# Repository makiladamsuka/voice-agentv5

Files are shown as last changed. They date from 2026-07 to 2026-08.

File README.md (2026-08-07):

# Nema — Multimodal Autonomous Campus Kiosk Robot

Nema is an end-to-end autonomous campus kiosk robot featuring real-time computer vision, closed-loop kinematic motor positioning, dynamic eye animations, 4-DOF greeting gestures, and a zero-latency natural language voice agent interface.

---

## 📸 Kiosk User Interface Screenshots

### 1. Main Campus Announcement Hub
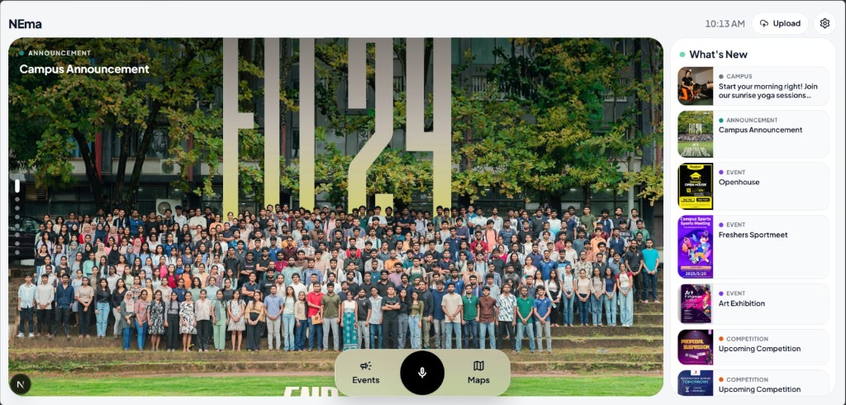
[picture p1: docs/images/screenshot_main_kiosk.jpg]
Main Campus Announcement Hub


### 2. Events & Competitions Grid
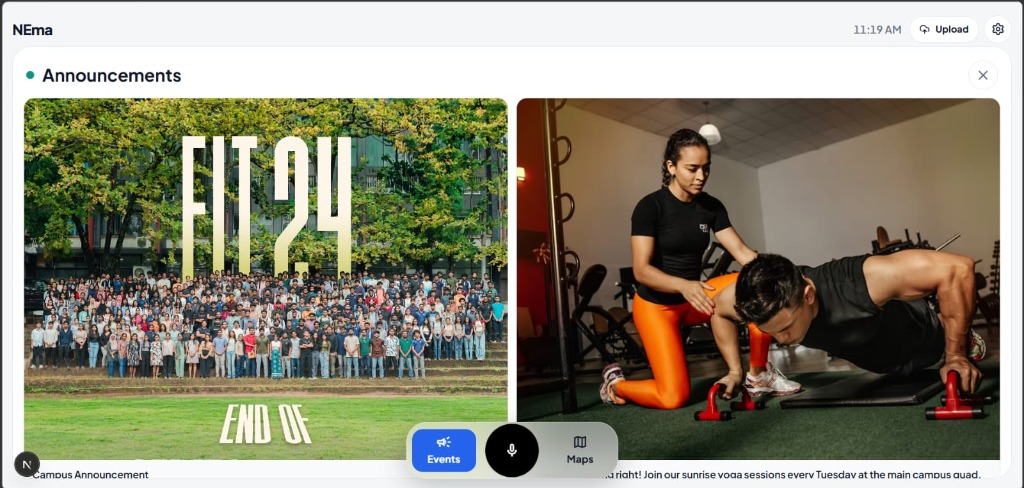
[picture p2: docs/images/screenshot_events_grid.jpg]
Events Grid


### 3. Tap-to-Talk Interactive Voice Chat
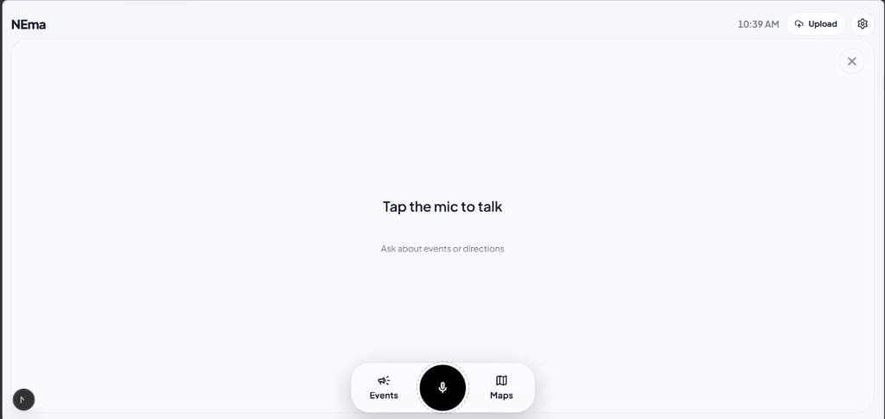
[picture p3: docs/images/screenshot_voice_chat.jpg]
Voice Chat


### 4. Interactive 3D Campus Maps
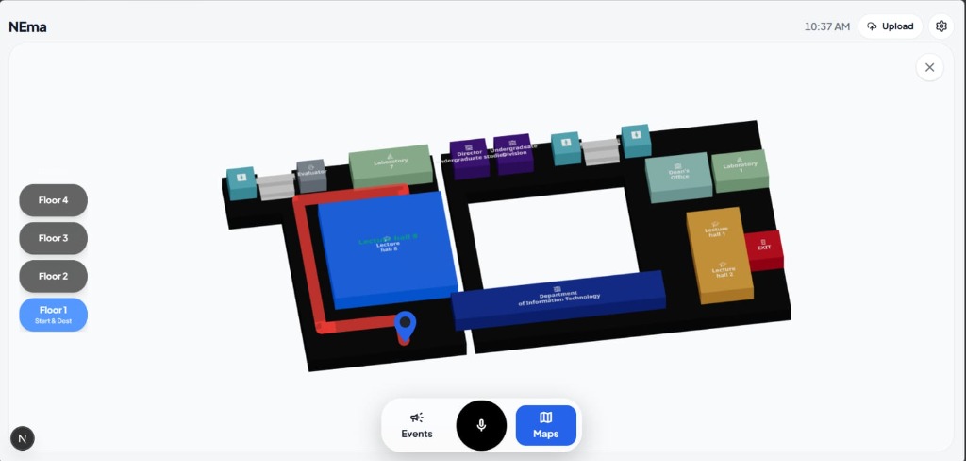
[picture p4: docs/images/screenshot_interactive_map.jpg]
Interactive Maps


### 5. Quick Destination & Faculty Navigation
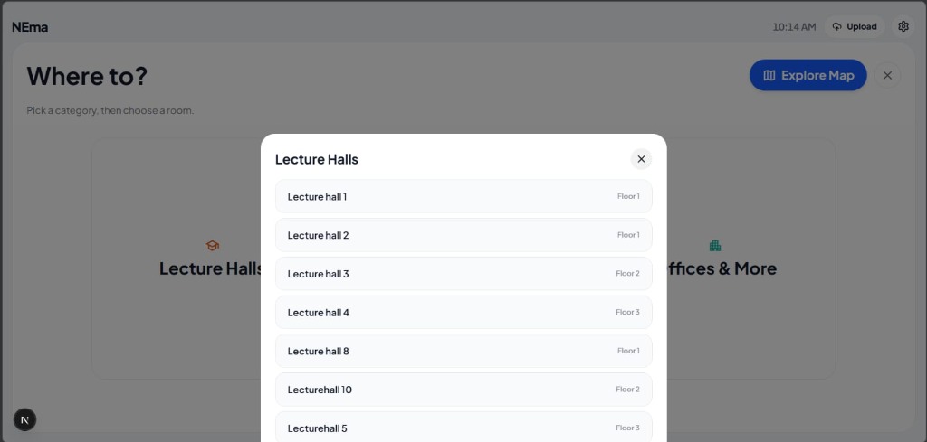
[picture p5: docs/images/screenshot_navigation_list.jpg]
Destination Navigation


---

## 📂 Quick Links & Documentation

- **🚀 [Quick Start & Setup Guide](docs/QUICK_START.md)** — Complete step-by-step instructions for fresh Raspberry Pi setup, config settings, and starting the kiosk stack.
- **🧠 [System Architecture & Specifications](docs/SYSTEM_ARCHITECTURE.md)** — Exhaustive technical details covering CPU core affinity, custom PCBs, Blackboard state bus, and NLU vector matching.
- **📦 [3D Printable STL Parts](hardware/3d_models/)** — 3D model files (.stl) for Nema's custom robot body and mounts.

---

## 🛠️ Hardware Stack Overview

- **Raspberry Pi 4 Model B (Brain):** Runs face-tracking, emotion engines, and the Next.js kiosk frontend.
- **ESP32 DevKit V1 (Muscles):** Controls servos (head pan/tilt, 4-DOF arms) and closed-loop DC base motors.
- **Raspberry Pi Zero 2 W (Voice Node):** Dedicated low-noise voice module running an INMP441 MEMS microphone.
- **3 Custom PCBs:** Custom circuit boards for the Pi 4 (eye screen outputs), ESP32 (motor control lines), and Pi Zero (mic module).

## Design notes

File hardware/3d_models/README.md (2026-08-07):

# Nema Kiosk Robot — 3D Component Models

Place your 3D printer files and CAD designs in this directory.

## Directory Structure

- `stl_parts/`  
  *Place your printable `.stl` or `.3mf` files here. These will render interactively directly in the web browser on GitHub.*

## Printing Guidelines (Recommended)

- **Filament:** PLA or PETG (PETG is recommended for load-bearing brackets and joints).
- **Infill:** 15% to 25% (Gyro / Grid infill for strength).
- **Supports:** Enable supports for overhang brackets.

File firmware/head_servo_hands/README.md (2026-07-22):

# head_servo_hands

**Baseline `head_servo` + four arm servos.** Same head/base protocol as `firmware/head_servo/`
(L/R spin, encoder moves, U/RL limit unlock, etc.) — face tracking keeps working.

## PCA9685 wiring

| PCA ch | Token | Servo |
|---|---|---|
| 4 | P | pan |
| 5 | T | tilt |
| 0 | A0 | MG996R_R — right shoulder raise |
| 2 | A1 | MG996R_L — left shoulder raise |
| 8 | A2 | SG90_R — right arm sweep |
| 9 | A3 | SG90_L — left arm sweep |

## Arm limits (deg) and home

| Servo | Min | Max | Home |
|---|-----|-----|---|
| A0 (R raise) | 47 | 124 | 47 |
| A1 (L raise) | 6 | 65 | 65 (rest down; lower angle = raised) |
| A2 (R sweep) | 44 | 78 | 64 |
| A3 (L sweep) | 70 | 102 | 87 |

Home = captured **raise low + min sweep** pose (`tests/captured_arm_limits.json`).

I2C: SDA=21, SCL=22, address `0x40`, 115200 baud USB serial.

## Flash

```bash
arduino-cli upload -p /dev/ttyUSB0 --fqbn esp32:esp32:esp32 firmware/head_servo_hands
```

Boot banner: `FW head_servo_hands_v5`

Arm PWM is **off at boot** until the Pi sends `A0..A3`. After **30 s** without an arm command, PWM turns off (Pi keepalive should send every &lt;1 s). Send `AO` to detach immediately. Head pan/tilt (ch 4/5) unchanged.

## Test arms

```bash
python tests/test_servo_arms_manual.py
```

## Note

`firmware/head_servo/head_servo.ino` stays head-only for `main`/baseline.
Flash this sketch when arms are connected; `start_robot.py` needs no code changes.

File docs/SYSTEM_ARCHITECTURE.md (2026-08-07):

# Voice Agent V5 — System Architecture & Technical Specification

**Project Title:** Voice Agent V5: Multimodal Autonomous Kiosk Robot  
**Document Version:** 5.4.0  
**Target Audience:** University Dean, Academic Evaluation Committee, Systems Architecture & Robotics Engineering Team  
**Author / Engineering Lead:** Voice Agent V5 Project Team  
**Date:** August 2026  

---

## 📋 Executive Summary & System Overview

**Voice Agent V5** is an integrated, end-to-end multimodal autonomous kiosk and physical robotic head/arm platform. Designed for high-foot-traffic campus environments, the system combines real-time computer vision, closed-loop kinematic motion control, sensor fusion, natural language understanding (NLU), and procedural graphics to deliver zero-latency human-robot interactions (HRI).

### Key Architectural Highlights
1. **Multimodal Perception Array:** Computer vision via OpenCV YuNet neural face detection, Bosch BMI160 6-DOF head IMU stabilization, and 3-zone ST VL53L0X Time-of-Flight (ToF) laser ranging via a TCA9548A I2C multiplexer.
2. **Centralized Shared-Memory Blackboard Architecture:** Decoupled thread-safe state bus (`core/blackboard.py`) using lock-free read concepts and CPU-friendly condition variables (`wait_for`) to eliminate polling latency while running at 0% idle CPU overhead.
3. **Distributed Hardware Controller Bridge:** Dedicated ESP32 NodeMCU microcontroller managing physical actuators (head pan/tilt, 4-DOF robotic arms, TB6612FNG motor driver base spin) via high-speed custom binary/ASCII serial wire protocol over USB UART.
4. **Zero-Latency NLU & Pre-Synthesized Speech Pipeline:** Local ChromaDB vector database with pre-synthesized 48kHz uncompressed audio cache combined with online LLM (Groq/OpenRouter) and offline local fallback runtime.
5. **Interactive Touchscreen Kiosk UI:** Next.js 14 React frontend rendering event posters, interactive maps, live voice waveforms, and real-time face greeting overlays.

```mermaid
graph TD
    subgraph "Perception Layer"
        CAM[GC2053 / Pi Camera v2] -->|Picamera2 / OpenCV| VT[YuNet Face & Hand Tracker]
        IMU[BMI160 6-DOF IMU] -->|Pi I2C 1 @ 0x69| IS[ImuService - Complementary Filter]
        TOF[3x VL53L0X ToF Array] -->|TCA9548A Mux @ 0x70| ESP32[ESP32 Microcontroller]
        MIC[Dedicated Pi Zero 2 W / INMP441 Mic] -->|Web Audio / Silero VAD| VA[Voice & NLU Pipeline]
    end

    subgraph "Core Decoupled Shared Memory"
        BB[(Blackboard Shared State Bus)]
    end

    subgraph "Actuation & Control Layer"
        SL[ServoLoop - Head PID & Wander]
        BC[BaseController - Closed-loop Fusion]
        AC[ArmController - Safety Envelope & Poses]
        EE[EmotionEngine - Mood State Machine]
        ER[EyeRenderer - 60FPS Procedural TFT]
    end

    subgraph "Hardware Communication Bridge"
        ASL[ArduinoServoLink Transport]
        PCA[PCA9685 PWM Driver @ 0x40]
        MOT[TB6612FNG Base Motor Driver]
    end

    VT -->|Write Bounding Box & Norm X/Y| BB
    IS -->|Write Roll/Pitch & Gyro Yaw| BB
    ESP32 -->|Stream PROX / ZONE Telemetry| ASL
    ASL -->|Write Proximity Vectors| BB
    VA -->|Write Voice State & RMS Amp| BB

    BB <-->|Read Targets / Write Pose| SL
    BB <-->|Read Pan Limit / Write Base Step| BC
    BB <-->|Read Gesture / Write Arm Joint Angles| AC
    BB <-->|Read Voice/Sensing / Write Mood| EE
    BB <-->|Read Emotion / Render TFT| ER

    SL -->|Pan/Tilt Cmds| ASL
    BC -->|Base Spin Cmds| ASL
    AC -->|Arm A0-A3 Cmds| ASL

    ASL <-->|USB Serial UART @ 115200| ESP32
    ESP32 -->|I2C Master SDA:21 SCL:22| PCA
    ESP32 -->|GPIO 25 PWM / 26,27 DIR| MOT
```

---

## 💻 Multiprocessing CPU Core Affinity & Allocation Strategy

To ensure zero micro-stutters in 48kHz audio playback while running compute-intensive neural vision inference, process scheduling on the Raspberry Pi 4 Model B (Quad-Core ARM Cortex-A72 @ 2.1 GHz) is explicitly pinned using `taskset -c 0-2 nice -n -5`:

```
+---------------------------------------------------------------------------------------------------+
|                                  Raspberry Pi 4 Quad-Core Allocation                              |
+-------------------+-----------------------+-----------------------+-------------------------------+
|    CPU Core 0     |      CPU Core 1       |      CPU Core 2       |          CPU Core 3           |
| (OS & Media Core) |    (Vision Core)      |   (Kinematics Core)   |        (NLU & Web Core)       |
+-------------------+-----------------------+-----------------------+-------------------------------+
| - Linux OS Kernel | - YuNet Neural Model  | - ServoLoop (PID Head | - Next.js Kiosk UI (:3000)    |
| - ALSA / PipeWire |   Face Tracker        |   Tracking @ 35-50Hz) | - Local NLU Server (:8765)    |
|   48kHz Audio     | - PyCamera2 Sensor    | - BaseController      | - ChromaDB Vector Store       |
| - Chromium Kiosk  |   Capture Feed        |   (Encoder+IMU Fusion)| - Python MediaServer (:8080)  |
|   Browser Engine  | - Skin-blob & Hand    | - ImuService & Arm    | - LiveKit WebRTC Agent        |
|   GPU Driver      |   Gesture Processing  |   Safety Envelope     |   Worker                      |
+-------------------+-----------------------+-----------------------+-------------------------------+
```

### Core Assignment Table

| Core ID | Assigned Processes / Threads | Priority (`nice`) | Rationale |
| :--- | :--- | :--- | :--- |
| **Core 0** | OS Kernel, PipeWire / ALSA Audio Engine, Chromium Kiosk Browser | `nice = 0` | Dedicated to real-time audio playback, USB I/O, and hardware-accelerated WebGL display rendering. |
| **Core 1** | OpenCV YuNet Face Detection (`core/face_tracking.py`), PyCamera2 | `nice = -5` | Isolated high-throughput matrix operations for neural computer vision inference without interfering with audio. |
| **Core 2** | `ServoLoop` (PID), `BaseController` (Fusion), `ArmController`, `ImuService` | `nice = -5` | High-frequency deterministic kinematic control loops ($35-50\text{ Hz}$) ensuring smooth servo movement. |
| **Core 3** | Next.js Server (:3000), NLU WS Server (:8765), ChromaDB, MediaServer (:8080) | `nice = 0` | Handles asynchronous network HTTP/WebSocket requests, vector embeddings, and LLM API streaming. |

---

## 🛠️ Complete Hardware Component Architecture & Specifications

The robot utilizes a heterogeneous, multi-bus hardware topology separating high-level neural inference from microsecond-level deterministic pulse-width modulation (PWM) and quadrature interrupt counting.

```
+---------------------------------------------------------------------------------------------------+
|                                   Raspberry Pi 4 Model B (Host Node)                             |
|  - ARM Cortex-A72 Quad-Core @ 2.1 GHz (Overclocked) | 8GB LPDDR4 SDRAM                            |
|  - VideoCore VI GPU | 256MB CMA Allocation | Raspberry Pi OS 64-bit Bookworm (Kernel 6.6)         |
+-------------------+---------------------------------------+---------------------------------------+
                    |                                       |
                    | USB Serial UART (115200 Baud)         | Hardware I2C 1 (SDA: GPIO2 / SCL: GPIO3)
                    v                                       v
+---------------------------------------------------+   +-------------------------------------------+
|             ESP32 Microcontroller                 |   |       Bosch BMI160 6-DOF Head IMU         |
|  - Dual-Core Xtensa LX6 @ 240 MHz                 |   |  - Gyroscope (Z-yaw integration)          |
|  - FreeRTOS Real-Time Kernel                      |   |  - Accelerometer (Roll/Pitch leveling)    |
+---------+-----------------------+-----------------+   +-------------------------------------------+
          |                       |
          | I2C Master (21/22)    | GPIO 25 PWM / 26,27 DIR
          | @ 400 kHz             v
          |                     +-------------------------------------------------------------------+
          |                     |                 TB6612FNG / L298N Base Motor Driver               |
          |                     | - Drives High-Torque N20 Geared Base Motor                        |
          |                     | - Dual Optical Quadrature Encoders (GPIO35 / GPIO34 Interrupts)   |
          |                     +-------------------------------------------------------------------+
          |
          +-------------------------------------------+
          |                                           |
          v @ Address 0x70                            v @ Address 0x40
+-----------------------------------+   +-----------------------------------------------------------+
|   TCA9548A 8-Ch I2C Multiplexer   |   |            PCA9685 16-Ch 12-Bit PWM Servo Driver          |
| - Ch 0: ST VL53L0X ToF (Left)     |   | - Ch 4: Head Pan Servo (25° .. 150°)                      |
| - Ch 1: ST VL53L0X ToF (Center)   |   | - Ch 5: Head Tilt Servo (100° .. 150°)                    |
| - Ch 2: ST VL53L0X ToF (Right)    |   | - Ch 0: Arm Joint A0 (MG996R Shoulder Pitch)              |
+-----------------------------------+   | - Ch 2: Arm Joint A1 (MG996R Shoulder Roll)               |
                                        | - Ch 8: Arm Joint A2 (SG90 Elbow Flex)                    |
                                        | - Ch 9: Arm Joint A3 (SG90 Wrist Sweep)                   |
                                        +-----------------------------------------------------------+
```

### Exhaustive Hardware Bill of Materials & Pinout Specification

| Subsystem Component | Part Model / Specification | Bus / Interface | Pin Connections / I2C Addr | Operational Role |
| :--- | :--- | :--- | :--- | :--- |
| **Main Compute Host** | Raspberry Pi 4 Model B (8GB) | System Bus | Broadcom BCM2711 | Core AI engine, NLU server, YuNet vision, Next.js UI |
| **Secondary Compute** | Raspberry Pi Zero 2 W | USB / WiFi | ARM Cortex-A53 | Dedicated low-power audio mic / remote endpoint node |
| **Microcontroller** | ESP32 DevKit V1 (30-pin) | USB Serial UART | `/dev/ttyUSB0` @ 115200 | Real-time FreeRTOS task runner, PWM, interrupts, ToF |
| **I2C Multiplexer** | TCA9548A 8-Channel Mux | ESP32 I2C Master | `0x70` (SDA: 21, SCL: 22) | Resolves I2C address conflicts for 3x VL53L0X sensors |
| **Left ToF Sensor** | ST VL53L0X Laser Ranging | TCA9548A Ch 0 | I2C `0x29` via Mux Ch0 | Measures spatial distance in Left zone (80..2200 mm) |
| **Center ToF Sensor**| ST VL53L0X Laser Ranging | TCA9548A Ch 1 | I2C `0x29` via Mux Ch1 | Measures spatial distance in Center zone (80..2200 mm) |
| **Right ToF Sensor** | ST VL53L0X Laser Ranging | TCA9548A Ch 2 | I2C `0x29` via Mux Ch2 | Measures spatial distance in Right zone (80..2200 mm) |
| **PWM Servo Driver**| PCA9685 16-Ch 12-Bit PWM | ESP32 I2C Master | `0x40` (SDA: 21, SCL: 22) | Generates 50 Hz PWM signals for head and 4-DOF arms |
| **Head Pan Servo** | Digital High-Torque Servo | PCA9685 Ch 4 | Pulse: 450-2600 µs | Neck Horizontal Rotation (-90° to +90° sweep) |
| **Head Tilt Servo** | Digital High-Torque Servo | PCA9685 Ch 5 | Pulse: 450-2600 µs | Neck Vertical Pitch (-45° to +45° sweep) |
| **Arm Joint A0** | MG996R Metal Gear Servo | PCA9685 Ch 0 | Pulse: 450-2600 µs | Right Arm Shoulder Pitch ($47^\circ .. 124^\circ$) |
| **Arm Joint A1** | MG996R Metal Gear Servo | PCA9685 Ch 2 | Pulse: 450-2600 µs | Right Arm Shoulder Roll ($6^\circ .. 65^\circ$) |
| **Arm Joint A2** | SG90 Micro Servo | PCA9685 Ch 8 | Pulse: 1000-2000 µs | Right Arm Elbow Flex ($44^\circ .. 78^\circ$) |
| **Arm Joint A3** | SG90 Micro Servo | PCA9685 Ch 9 | Pulse: 1000-2000 µs | Right Arm Wrist Sweep ($70^\circ .. 102^\circ$) |
| **Base Motor Driver**| TB6612FNG / L298N H-Bridge | ESP32 GPIO | PWM: 25, AIN1: 26, AIN2: 27 | Drives N20 DC base geared spin motor (20 kHz PWM) |
| **Base Encoders** | Dual Optical Quadrature | ESP32 GPIO Interrupt | A: GPIO35, B: GPIO34 | Measures base rotation (31.167 counts/degree) |
| **Head IMU** | Bosch BMI160 6-DOF | Pi 4 Hardware I2C 1 | `0x69` (SDA: 2, SCL: 3) | 25 Hz Head horizon auto-leveling & body gyro yaw |
| **Camera Sensor** | GC2053 / Pi Camera v2 | CSI Ribbon Cable | MIPI CSI-2 Interface | 1080p video feed / 640x360 YuNet face detection |
| **MEMS Microphone** | INMP441 Omnidirectional | I2S Bus (Pi Zero 2 W)| SCK: 18, WS: 19, SD: 22 | 24-bit 48kHz I2S Digital MEMS Microphone |
| **Kiosk Touchscreen**| 10.1" 1024x600 IPS Display | HDMI 0 + USB Touch | HDMI 0 (Custom Timings) | Primary touchscreen kiosk display |
| **Eye TFT Displays** | Dual SPI 1.28" Round LCDs | Pi 4 SPI1 Bus | `dtoverlay=spi1-3cs` | 60 FPS Procedural TFT animated eye rendering |
| **Audio Interface** | USB External Sound Adapter | USB 2.0 / ALSA Card 3 | ALSA / PipeWire | Zero-resampling 48 kHz 16-bit uncompressed PCM I/O |

---

## 📡 Hardware Interconnection & Firmware ASCII Protocol Specification

The host Raspberry Pi 4 communicates with the ESP32 microcontroller running `firmware/head_servo_hands/head_servo_hands.ino` via USB Serial (`/dev/ttyUSB0` at 115,200 baud, 8N1).

```
Host (Raspberry Pi 4)                                     Embedded Controller (ESP32)
   |                                                                  |
   | --- Downstream Command: "P 12.5 T -4.0\n" -------------------->  | (Head Pan/Tilt target)
   | --- Downstream Command: "A0 47.0 A1 65.0 A2 64.0 A3 87.0\n" ->  | (Arm Joint Targets)
   | --- Downstream Command: "B -45.0\n" --------------------------->  | (Base Spin -45 deg)
   | --- Downstream Command: "AO\n" -------------------------------->  | (Detach Arm PWM Power)
   |                                                                  |
   |  <-- Upstream Ack: "OK P13 T-4\n" ----------------------------   | (Command Acknowledged)
   |  <-- Upstream Telemetry: "POS -1402 DEG -45.0 CPD 31.17 BUSY 0"  | (Base Odometry Update)
   |  <-- Upstream Event: "PROX A=L V=-120 D=450 C=3\n" -----------   | (Proximity Approach)
   |  <-- Upstream Matrix: "ZONE L=1 C=0 R=0\n" -------------------   | (Occupancy Matrix)
   |  <-- Upstream ToF Stream: "TOF L=840 C=1250 R=1800\n" --------   | (Raw Distance Stream)
```

### Downstream Wire Protocol (Pi → ESP32 Firmware)

| Command String | Parameters & Syntax | Firmware Execution (`head_servo_hands.ino`) |
| :--- | :--- | :--- |
| `P <pan> T <tilt>` | `pan`: [-90..+90], `tilt`: [-45..+45] | Writes pan/tilt servo angles to PCA9685 Channels 4 and 5. Quantized to 0.2° to prevent chatter. |
| `A0 <a0> A1 <a1> A2 <a2> A3 <a3>` | `a0..a3`: float joint degrees | Writes 4-DOF arm joint angles to PCA9685 Channels 0, 2, 8, 9. Resets idle detach timer (`ARM_IDLE_DETACH_MS = 30000`). |
| `AO` | None | Detaches arm servo PWM channels (0, 2, 8, 9) to stop SG90 micro-servo noise, buzz, and heating. |
| `B <deg>` | `deg`: float relative degrees | Initiates TB6612FNG motor base spin using closed-loop quadrature encoder interrupts (`ENC_A`, `ENC_B`). |
| `C <code>` | `code`: integer command | Calibration command (e.g. `C1` resets base encoder origin to 0). |
| `E <enable>` | `enable`: `0` or `1` | Motor safety gate: `0` disables TB6612FNG PWM output, `1` enables motor drivers. |
| `V` | None | Queries firmware banner version (e.g. `FW head_servo_hands_v5`). |

### Upstream Telemetry & Event Protocol (ESP32 Firmware → Pi)

| Packet Prefix | Exact Format & Regex Match | Firmware Logic & Source |
| :--- | :--- | :--- |
| **Servo Ack** | `OK P<pan> T<tilt>` | Emitted after PCA9685 register write confirmation. |
| **Base Status** | `POS <cnt> DEG <deg> CPD <cpd> BUSY <0|1>` | Emitted at 20 Hz during base motion. Contains raw quadrature encoder ticks and busy state. |
| **Proximity Approach**| `PROX A=<zone> V=<vel> D=<dist> C=<conf>` | Emitted when a person approaches. `zone` (`L`/`C`/`R`), approach velocity ($\text{mm/s}$), distance ($\text{mm}$), confidence. |
| **Proximity Depart**  | `PROX D=<zone> V=<vel> D=<dist> C=<conf>` | Emitted when a person leaves a zone. |
| **Occupancy Matrix**  | `ZONE L=<0|1> C=<0|1> R=<0|1>` | 3-Zone real-time presence occupancy state matrix. |
| **ToF Sensor Stream**  | `TOF L=<d0> C=<d1> R=<d2>` | 10 Hz raw distance stream from ST VL53L0X sensors via TCA9548A channel switching. |

---

## 🧠 The Shared-Memory Blackboard Architecture (`core/blackboard.py`)

At the core of Voice Agent V5 is a centralized, thread-safe, decoupled **Blackboard Shared Memory Bus**.

Instead of direct inter-thread coupling, data producers (Vision, IMU, Audio, ESP32 Serial) write state changes to the Blackboard. Data consumers (ServoLoop, BaseController, EmotionEngine, EyeRenderer, Next.js WS Server) read state atomically.

```
       PRODUCERS                                                 CONSUMERS
+--------------------+                                    +--------------------+
|  FaceTracker (AI)  | ----\                        /---> |  ServoLoop (PID)   |
+--------------------+      \                      /      +--------------------+
|   ImuService (IMU) | ----- \                    / ----> | BaseController     |
+--------------------+        \                  /        +--------------------+
| VoiceService (NLU) | -------> +----------------+ -----> | EmotionEngine      |
+--------------------+          |   BLACKBOARD   |        +--------------------+
|  ESP32 Serial Link | -------> | Shared Memory  | -----> | EyeRenderer (TFT)  |
+--------------------+        / +----------------+ \ ----> | ArmController      |
|  Proximity Engine  | ------/                      \ ---> | Next.js Kiosk UI   |
+--------------------+                                    +--------------------+
```

### Mutex Synchronization & Zero-CPU Event Notification

The Blackboard implements atomic `read()`, `write()`, and `wait_for()` primitives using `threading.Lock()` and mapped `threading.Condition()` variables:

1. **Atomic Read/Write (`read()`, `write()`):**
   ```python
   def write(self, **kwargs: Any) -> None:
       notified = []
       with self._lock:
           for key, value in kwargs.items():
               setattr(self, key, value)
               if key in self._conditions:
                   notified.append(self._conditions[key])
       # NOTIFY OUTSIDE LOCK TO PREVENT PRIORITY INVERSION
       for cond in notified:
           with cond:
               cond.notify_all()
   ```
2. **Zero-CPU Wait Primitive (`wait_for()`):**
   Subsystem threads (such as `BaseController` or `AnimationEngine`) call `bb.wait_for("field_name", timeout=5.0)`. Instead of burning CPU cycles in `while True: time.sleep(0.01)` polling loops, caller threads suspend at **0% CPU** until `bb.write()` emits a condition notification.

---

## ⚙️ Multi-Threaded Subsystem Execution & Control Logic

The Python backend starts several synchronized worker threads inside `start_robot.py`:

### 1. Vision Subsystem (`core/face_tracking.py`)
- **Neural Model:** OpenCV DNN with YuNet lightweight face detection (`face_detection_yunet_2023mar.onnx`).
- **Resolution Strategy:** Captures camera feed at 1080p for crisp display rendering, but downsamples to 640x360 for detection inference to conserve Pi CPU.
- **Adaptive Region of Interest (ROI):** Once a face is detected, the algorithm crops a bounding box sub-window (padded by 1.6x) for subsequent frames. Performs full-frame scans every 20 frames or upon target loss, cutting CPU usage by ~40%.
- **Zero-CPU Speech Pause Mode:** When `bb.read("user_speaking", "agent_speaking")` flags active audio, camera capture and YuNet inference pause automatically. This frees ~50ms/frame CPU capacity during voice synthesis.

### 2. Servo & Kinematics Control Loop (`core/servo_loop.py`)
- **Proportional-Integral-Derivative (PID) Control:** Translates normalized face coordinates ($x, y \in [-1.0, +1.0]$) into smooth head pan/tilt angle commands:
  $$\Delta \theta_{\text{pan}} = K_p \cdot e_x + K_d \cdot \frac{de_x}{dt}$$
- **Proactive Neck Counter-Rotation:** When the base spins to align with a user, the neck pan counter-rotates in exact opposition ($\text{Pan}_{\text{neck}} = -\theta_{\text{base}}$) to keep the camera locked on the user's face during body movement.
- **Wander & Search Generators:** When no target is detected for $>5.0$ seconds, the system enters an organic wandering state, gliding head pan/tilt angles using smooth S-curve interpolation.

### 3. Base Controller & Odometry Fusion (`core/base_controller.py` & `lib/yaw_home_tracker.py`)
- **Head-Lead Base Alignment:** If the head pan angle exceeds $\pm 12.0^\circ$ relative to the central body chassis, the `BaseController` commands a base spin step to align the body with the head.
- **Sensor Fusion:** Merges relative quadrature encoder counts ($31.167\text{ counts/degree}$) with the BMI160 gyro integrated $Z$-yaw. If physical base wheel slip occurs, the IMU gyro overrides encoder odometry to guarantee accurate orientation tracking.

### 4. IMU Head Horizon & Leveling (`core/imu_service.py`)
- **Complementary Filter:** Combines accelerometer tilt angles with integrated gyroscope angular velocities:
  $$\theta_{\text{pitch}} = \alpha \cdot (\theta_{\text{pitch}} + \omega_y \cdot \Delta t) + (1 - \alpha) \cdot \theta_{\text{accel\_y}}$$
  where $\alpha = 0.98$.
- **Active Horizon Compensation:** Adjusts tilt servo target commands dynamically to keep the camera horizon perfectly level, even when the robot body tilts or moves across uneven surfaces.

---

## 🎙️ Multimodal Voice Pipeline & NLU System Architecture

The voice architecture provides zero-latency conversational AI through a 5-tier hybrid strategy:

```mermaid
sequenceDiagram
    autonumber
    actor User
    participant UI as Kiosk UI / Mic
    participant NLU as NLU Server (:8765)
    participant CDB as ChromaDB Vector Store
    participant LLM as Groq / OpenRouter API
    participant SPK as Audio Output (PipeWire)
    participant BB as Blackboard Shared State

    User->>UI: Speaks Question ("Where is the Hackathon?")
    UI->>UI: Web Audio Silero VAD detects end-of-speech
    UI->>NLU: Transmitted PCM Audio / Transcript (WebSocket)
    NLU->>BB: write(user_speaking=True, conv_state="thinking")
    
    rect rgb(240, 248, 255)
        note over NLU,CDB: Zero-Latency Local Vector Search
        NLU->>CDB: Query Utterance Embedding
        CDB-->>NLU: Match Found (Distance < 0.25, Audio: cached_event_42.wav)
    end

    alt Local Cache Hit (0ms Latency)
        NLU->>SPK: Play pre-synthesized 48kHz WAV audio
    else Local Cache Miss (Fallback to Cloud LLM)
        NLU->>LLM: Stream Prompt + Event Context
        LLM-->>NLU: Stream Response Tokens
        NLU->>NLU: Live Deepgram / Edge TTS Synthesis
        NLU->>SPK: Stream Audio Packets
    else Network Offline (Local Runtime Fallback)
        NLU->>NLU: Local Regex Router + Offline TTS (voice/offline_voice/runtime.py)
        NLU->>SPK: Play Local Synthesized Audio
    end

    NLU->>BB: write(agent_speaking=True, conv_state="speaking")
    loop Every 20ms Audio Frame
        SPK->>BB: write(amplitude_fast=RMS_val)
        BB->>UI: Update Waveform UI & Lip Sync
    end
    NLU->>BB: write(agent_speaking=False, conv_state="idle")
```

### Detailed NLU Workings & Latency Minimization Strategy

1. **Pre-Indexing Phase (`intent_compiler.py`):**
   - **Poster Parsing:** Vision LLMs parse event poster images in `assets/events/` into structured JSON (title, date, location, description).
   - **Utterance Generation:** Generates synthetic user query variations for each poster.
   - **Audio Pre-Synthesis:** Synthesizes uncompressed 48kHz WAV audio into `assets/audio_cache/`.
   - **ChromaDB Vector Store:** Encodes text utterances into **384-dimensional dense vector embeddings** using the **`all-MiniLM-L6-v2`** ONNX / SentenceTransformer model (`embedding_functions.DefaultEmbeddingFunction()`). Indexes embeddings into the persistent local ChromaDB database (`voice/event_db/`).

2. **Runtime Voice Capture & Silero VAD:**
   - Client mic captures speech; **Silero VAD** (Web Audio) detects voice activity and signals exact end-of-speech.

3. **0ms Synthesis Latency Local Cache Hit:**
   - User utterance is encoded into a $384\text{-D}$ embedding using `all-MiniLM-L6-v2` and matched via **Cosine Similarity**. If the cosine vector distance is $< 0.25$, the server plays the matching pre-synthesized 48kHz `.wav` file with **0ms synthesis delay** and zero API cost.

4. **Cloud LLM & Live TTS Fallback:**
   - If no local vector match exists, the request falls back to online LLMs (Groq Llama 3 70B / OpenRouter) and streams real-time TTS audio via Deepgram.

5. **Offline Local Engine Fallback:**
   - If internet connectivity drops, the system dynamically switches to `voice/offline_voice/runtime.py` using local regex domain routing and Pygame audio playback.

---

## 💡 Academic Defense Q&A Section

### Question 1: Why do we use a separate Raspberry Pi Zero 2 W with INMP441 I2S MEMS mic sensors instead of plugging directly into the Pi 4?
> **Answer (Hardware Pinout Conflict & Signal Isolation Rationale):**
> 1. **I2S vs Dual SPI Hardware Pin Collision:** On the Raspberry Pi 4 Model B, driving dual hardware SPI displays (`SPI0` for touchscreen interfaces and `SPI1` via `dtoverlay=spi1-3cs` for dual 60 FPS animated TFT round eyes) requires GPIO pins 16, 17, 18, 19, 20, and 21. However, the Pi 4's hardware I2S PCM audio bus (required by the INMP441 MEMS microphone) shares those **exact same physical pins**: `GPIO18 (PCM_CLK)`, `GPIO19 (PCM_FS)`, `GPIO20 (PCM_DIN)`, and `GPIO21 (PCM_DOUT)`. Operating INMP441 I2S audio simultaneously with dual SPI TFT eye displays on a single Pi 4 causes hardware pinout collisions and severe DMA channel lockups.
> 2. **Electromagnetic Noise & Motor Isolation:** Placing the MEMS microphone directly on the main chassis near high-frequency motor PWM drivers (20 kHz) and PCA9685 clock lines introduces electromagnetic interference (EMI) and physical motor chassis noise into the microphone input. Using a dedicated **Pi Zero 2 W** node isolates the microphone physically and electrically, transmitting clean, noise-cancelled 48kHz audio over network/USB with zero pin conflict.

### Question 2: How does the system guarantee zero audio micro-stutters while running complex computer vision neural networks on embedded hardware?
> **Answer:**
> 1. **Process CPU Core Pinning (`taskset`):** The Python orchestrator pins neural vision inference to CPU Core 1 and kinematic control loops to CPU Core 2, leaving CPU Core 0 exclusively for PipeWire/ALSA 48kHz audio playback and Chromium WebGL rendering.
> 2. **Zero-CPU Speech Pause Mode:** When speech activity is detected, YuNet face detection automatically pauses or drops to 2 FPS. This frees ~50ms/frame CPU capacity during voice streaming.

---

## 🛠️ Complete Tools, Frameworks & Libraries Reference Matrix

| Category | Tool / Library Name | Version / Specification | Technical Role & Usage in Project |
| :--- | :--- | :--- | :--- |
| **Computer Vision** | **OpenCV** (`opencv-python`) | 4.8+ | Frame manipulation, color space conversion, and DNN inference execution |
| | **YuNet ONNX Model** | `2023mar.onnx` | Lightweight face detection neural model optimized for ARM CPU execution |
| | **Picamera2** | System Package | Native Raspberry Pi OS camera stack for zero-copy 1080p video streaming |
| **Voice & Audio** | **Silero VAD** | Web Audio / ONNX | High-precision Voice Activity Detection for detecting end-of-speech |
| | **Deepgram API** | REST / WebSocket | High-speed cloud Speech-to-Text (STT) and Text-to-Speech (TTS) synthesis |
| | **PipeWire / ALSA** | 1.0+ | Linux audio server enforcing zero-resampling 48kHz 16-bit uncompressed audio |
| | **Pygame Mixer** | 2.5+ | Ultra-low latency local WAV audio file playback engine |
| **NLU & Vector DB** | **ChromaDB** | 0.4+ | Persistent local vector database for storing and querying intent embeddings |
| | **Groq API** | Llama 3 70B | Cloud LLM processing fallback queries with $<500\text{ ms}$ time-to-first-token |
| | **OpenRouter API** | Multi-Model API | Secondary cloud LLM gateway for poster text extraction and intent generation |
| | **VADER Sentiment** | `voice/sentiment.py` | Rule-based sentiment analysis driving dynamic robot eye color expressions |
| **Frontend Kiosk** | **Next.js** | 14 (React 18) | Touchscreen kiosk application, SSR rendering, and Web Audio VAD capture |
| | **TailwindCSS** | 3.3+ | Utility-first styling for responsive kiosk layouts |
| | **LiveKit WebRTC SDK** | React SDK | Low-latency WebRTC audio streaming between frontend kiosk and backend agent |
| **Embedded & C++** | **FreeRTOS** | ESP32 Core | Real-time dual-core task scheduling on ESP32 microcontroller |
| | **Adafruit PCA9685** | Arduino Library | I2C PWM driver control for 50 Hz head and 4-DOF arm servos |
| | **Adafruit VL53L0X** | Arduino Library | Laser ranging driver for 3x Time-of-Flight spatial proximity sensors |
| | **SMBus2** | Python Library | Hardware I2C communication library for Bosch BMI160 head IMU sensor |

---

## 📜 Conclusion

The **Voice Agent V5 Architecture** demonstrates a robust engineering solution for multimodal human-robot interaction. By decoupling heavy neural inference from deterministic hardware control through a high-performance **Blackboard Shared State Bus**, isolating compute roles across **pinned CPU cores**, and bridging compute layers over a resilient **Serial Wire Protocol**, the system achieves low-latency, real-time performance on cost-effective embedded hardware.

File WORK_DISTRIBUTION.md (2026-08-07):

# Voice Agent Kiosk - Project Work Distribution

This document outlines the comprehensive work distribution for the Voice Agent Kiosk project. The system is a complex integration of mechanical design, embedded electronics, AI-driven computer vision, natural language processing, and interactive web interfaces.

The workload has been distributed among the 5 team members based on their specific hardware and software assignments.

---                                                                                                                                          

## 1. Major Subsystems Identified 

To ensure complete end-to-end project delivery, the system is broken down into the following major subsystems:

- **Hardware:** Microcontrollers (Pi, Pi Zero), Displays (TFT), Cameras, Audio peripherals.
- **Embedded Systems:** Firmware, OS configuration, and low-level communication protocols.
- **PCB Design:** Custom circuit board layout and schematic design.
- **Mechanical Design:** 3D modeling, chassis design, and structural integrity.
- **Power System:** Battery management, voltage regulation, and power distribution.
- **Sensors:** Time-of-Flight (ToF), Proximity (Proxy meter), and IMU.
- **Motor Control:** Closed-loop control using encoder motors.
- **Raspberry Pi Software:** High-level orchestration, process management, and node communication.
- **AI Modules:** Inference engines for vision, gesture, and NLP.
- **Voice Processing:** Wake-word detection, speech-to-text, and audio filtering.
- **Computer Vision:** Real-time camera feeds, face tracking, and gesture recognition.
- **Navigation:** Spatial mapping, IMU tracking, and pathfinding.
- **User Interface:** Interactive 3D map kiosks, web dashboards, and robotic facial expressions.
- **Backend:** Cloud API integrations (Deepgram), server routing, and state management.
- **Testing:** Unit, integration, and user-acceptance testing.
- **System Integration:** Physical assembly and software pipeline merging.
- **Documentation:** Architectural diagrams, API specs, and project reports.

---

## 2. Team Member Assignments

### 👤 Makila
**Role: Lead UI/UX, Vision & Mechanical Designer**
Makila bridges the physical and digital interface of the robot, ensuring it looks approachable and tracks users intelligently.

**Assigned Tasks & Subsystems:**
*   **3D Design (Mechanical Design):** Designing the physical chassis, camera mounts, and display housings.
*   **Face Tracking Pi Camera (Computer Vision / AI / Hardware):** Implementing the vision pipeline to detect and continuously track human faces using the primary Pi Camera.
*   **Emotion with TFT Displays (User Interface / Embedded Systems):** Programming the TFT screens to render dynamic, responsive robotic facial expressions (eyes/emotions) based on system state.
*   **Web Design (User Interface / Backend):** Designing and developing the interactive web kiosk (frontend and backend endpoints) for user interaction.

**Components & Technologies Used:**
*   **Hardware/Sensors:** Raspberry Pi Camera Module, TFT SPI/I2C Displays, 3D Printed Chassis (PLA/PETG).
*   **Software/Tech:** OpenCV, Mediapipe/Yunet (Face Tracking), React/Next.js & TailwindCSS (Web UI), Python (Pygame/Pillow for TFT), SolidWorks/Fusion360 (3D Modeling).

---

### 👤 Ruwan
**Role: Motion & Gesture Intelligence Lead**
Ruwan focuses on the spatial awareness of the robot and how it interprets physical human interactions.

**Assigned Tasks & Subsystems:**
*   **PCB Design (PCB Design):** Designing the custom printed circuit boards required to interface the Raspberry Pi with the various sensors and motors securely.
*   **Hand Control "Hi, Bye" & Hand Gestures (Computer Vision / AI Modules):** Training and implementing the machine learning models required to detect and interpret specific human hand gestures.
*   **IMU Implementation (Sensors / Navigation):** Integrating the Inertial Measurement Unit to track the robot's physical orientation, tilt, and acceleration for smooth movement and balance.

**Components & Technologies Used:**
*   **Hardware/Sensors:** Custom PCB (FR4), MPU6050/BNO085 (IMU sensor), Raspberry Pi Camera Module.
*   **Software/Tech:** Altium/KiCad/EasyEDA (PCB design), OpenCV, Mediapipe (Hand Landmarks), Python, I2C/SPI protocols.

---

### 👤 Vihanga
**Role: Navigation & Electronics Hardware Lead**
Vihanga is responsible for the robot's internal nervous system (custom circuitry) and its understanding of the environment.

**Assigned Tasks & Subsystems:**
*   **Map Design (Navigation / User Interface):** Architecting the internal spatial map (2D/3D graphs) and the logic for the robot to understand where it is and where it can go.
*   **ToF Sensor Setup (Sensors / Embedded Systems):** Integrating Time-of-Flight sensors for accurate distance measurement and obstacle avoidance.
*   **Proxy Meter Setup (Sensors):** Configuring proximity sensors for close-range environmental awareness and safety.

**Components & Technologies Used:**
*   **Hardware/Sensors:** VL53L0X / VL53L1X (Time-of-Flight sensors), Ultrasonic/Infrared Proximity sensors (Proxy meter), I2C Multiplexers (TCA9548A).
*   **Software/Tech:** Python, ROS (Robot Operating System) or custom graph-based pathfinding (A* / Dijkstra), React Three Fiber (for 3D UI Map).

---

### 👤 Devinda
**Role: Actuation & Systems Integration Lead**
Devinda turns the software commands into physical movement and ensures the hardware is physically constructed correctly.

**Assigned Tasks & Subsystems:**
*   **Encoder Motor Use (Motor Control / Embedded Systems):** Writing the closed-loop PID control software to drive the motors precisely using encoder feedback, ensuring accurate locomotion.
*   **Assembling PCB & Hardware (Hardware / System Integration):** Physically soldering the PCBs, wiring the harnesses, integrating the power systems, and assembling the final physical robot.

**Components & Technologies Used:**
*   **Hardware/Sensors:** DC Gear Motors with Encoders, Motor Drivers (L298N/TB6612FNG), Batteries (LiPo/18650), Jumper wires, Soldering equipment.
*   **Software/Tech:** PID Control algorithms, PWM (Pulse Width Modulation), Python/C++ (for precise timing).

---

### 👤 Methoo
**Role: Voice, NLP & Edge Audio Lead**
Methoo handles the entire conversational pipeline, giving the robot its ability to hear, understand, and respond.

**Assigned Tasks & Subsystems:**
*   **Voice Detection (Voice Processing):** Implementing local wake-word detection and silence-trimming logic.
*   **Deepgram & Natural Language Processing (AI Modules / Backend):** Integrating the Deepgram API for blazing-fast speech-to-text, and handling the NLP pipeline to determine user intent.
*   **USB Microphone with Pi Zero (Hardware / Embedded Systems):** Setting up a satellite Pi Zero dedicated entirely to high-fidelity audio capture via a USB microphone array, ensuring the main Pi is not bottlenecked.

**Components & Technologies Used:**
*   **Hardware/Sensors:** Raspberry Pi Zero (W/2W), USB Microphone Array (e.g., ReSpeaker), Speakers.
*   **Software/Tech:** Deepgram API (Speech-to-Text), Wake-word engines (Porcupine/Snowboy), NLP libraries (NLTK/spaCy/LLM), WebSockets/REST APIs.

---

## 3. Shared Responsibilities

While the tasks above are highly specialized, the following subsystems require collaborative effort across all members:

*   **Power System:** Devinda (Assembly) and Vihanga (PCB Design) must collaborate to ensure the batteries and voltage regulators can handle the load of the Pi, Pi Zero, Motors, and TFTs.
*   **Raspberry Pi Software:** All members must ensure their individual Python scripts/modules communicate efficiently over the shared system architecture (e.g., WebSockets, ROS, or local sockets).
*   **Testing & System Integration:** Combining Vihanga's map, Devinda's motors, Ruwan's IMU, Makila's face tracking, and Methoo's voice commands into a single, cohesive, bug-free system.
*   **Documentation:** Every member is responsible for documenting their specific subsystems, APIs, wiring diagrams, and setup instructions.

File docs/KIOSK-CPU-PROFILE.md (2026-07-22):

# Kiosk CPU profile (`config.kiosk.yaml`)

This document describes what changes when you run the Pi with the **kiosk CPU profile** instead of full `config.yaml`. Use this profile when the same Pi runs **backend + Next.js + Chromium** together.

```bash
CONFIG_PATH=config.kiosk.yaml python start_robot.py start
# or
./scripts/launch-kiosk-stack.sh
```

**Design priority:** stable voice audio and lower CPU — not maximum vision fidelity or base motion during conversation.

---

## Quick summary

| Area | Kiosk behavior |
|---|---|
| Voice (LiveKit, local mic/speaker) | **On** — Pi captures mic and plays TTS on speakers |
| Head wander / idle glances | **On** — head still looks around when no face |
| Voice “thinking” head bob | **On** — during `conv_state: thinking` |
| ToF stream + PROX detection | **On** — ESP32 ToF data still ingested |
| ToF approach **base turns** | **On when idle** — **blocked during voice session** |
| ToF approach **head glance** | **On during voice** — head turns toward L/R approach |
| Base idle wander / spins | **On** — follows head + random turns when idle (still frozen during voice) |
| Face tracking during conversation | **Reduced / paused** while listening or speaking |
| Debug 3D dashboard (`:8082`) | **Off by default** — use `DEBUG_VIZ=1` to enable |
| Bye-wave hand gestures | **Off** |

---

## What is reduced or disabled

### Vision and face tracking

| Setting | `config.yaml` (full) | `config.kiosk.yaml` |
|---|---|---|
| Camera capture | 1920×1080 | 640×480 |
| YuNet detect resolution | 1280×720 | 480×270 |
| Vision FPS | 10 | 5 (2 during voice) |
| MJPEG stream FPS | 8 | 6 |
| Pause camera during voice | — | **Yes** (`vision_pause_on_audio: true`) |

While a voice session is active, face tracking **slows down or pauses** when the user or agent is speaking/listening. This saves CPU for audio and STT.

### Control loop rates

| Service | Full config | Kiosk (normal) | Kiosk (during voice) |
|---|---|---|---|
| Servo loop | 80 Hz | 35 Hz | **16 Hz** |
| Arms | 50 Hz | 35 Hz | **12 Hz** |
| Base controller | — | 25 Hz | **10 Hz** |
| IMU sample rate | 100 Hz | 25 Hz | 25 Hz |
| Eye renderer | 40 fps | 12 fps | 12 fps |
| Talk gesture poll | 50 Hz | ~12.5 Hz | ~12.5 Hz |
| Emotion engine | default | default | **6 Hz** |

Rates during voice come from `voice_profile` in `config.kiosk.yaml`:

```yaml
voice_profile:
  arms_loop_hz: 12
  servo_loop_hz: 16
  servo_send_hz: 16
  mixer_loop_hz: 16
  base_loop_hz: 10
  emotion_loop_hz: 6
  freeze_base_during_voice: true
  conv_nod_scale: 0.2
  viz_pose_hz: 0
```

### Motion and features turned off

- **Debug dashboard** — `debug_viz.auto_start: false` (port 8082). Enable with `DEBUG_VIZ=1` or set `auto_start: true`.
- **Viz pose publishing** — `viz_pose_hz: 0` (no pose stream to debug UI unless viz is on).
- **Bye wave** — `bye_wave.enabled: false`.
- **Base wander** — `base.wander_enabled: true` (idle plate follow + random turns; still paused during voice via `freeze_base_during_voice`).
- **Base motion during voice** — `freeze_base_during_voice: true` (no track follow, ToF base turns, memory base moves, etc. while LiveKit session is connected).
- **Face greeting arm gestures** — off in both profiles (`face_greeting_arm.enabled: false`).

### Backend audio path (kiosk voice)

When `voice.local_mic` and `voice.local_speaker` are true in `config.kiosk.yaml`:

- Microphone is captured on the **Pi** (not the browser).
- TTS plays on **Pi speakers** (browser agent audio is muted).
- AEC reverse stream is fed from the local speaker into the mic APM for echo cancellation.

---

## What still works

### ToF approach

ToF sensing and PROX approach detection **still run**:

- ESP32 ToF lines are parsed (`TofStreamHandler`).
- `proximity.enabled: true`, `tof_turn_enabled: true`.
- Investigate / scan behavior is enabled (`proximity.investigate.enabled: true`).

**During an active voice session:**

- **Base does not turn** toward approach (`freeze_base_during_voice`).
- **Head can glance** toward L/R approach zones (short `prox_glance_*` motion).
- If already tracking a face, investigate may run as a **head-only** scan.

**When not in voice**, full approach behavior (including base turns) works as configured.

### “Wondering” / wander

Two different behaviors:

| Behavior | Kiosk |
|---|---|
| **Head wander** — idle glances, organic look-around (`ServoLoop` wander mode) | **On** |
| **Thinking wander holds** — longer pauses while “thinking” | **On** (`wander_thinking_hold_chance`, etc.) |
| **Conversation thinking bob** — head motion when `conv_state: thinking` | **On** |
| **Base wander** — plate spins when idle | **On** (blocked during voice session) |
| **Random large base turns** | **On** |

So the robot still **looks around with its head**; it does **not** do idle **base** wandering on kiosk.

### Other behavior still active

- Face tracking (when vision is not paused).
- Person memory and last-seen search.
- Face greeting (voice hello when new face seen).
- Talk gestures during agent speech (slower poll rate).
- Surroundings / conversation emotions.
- Proximity investigate when not blocked by voice/base freeze.

---

## Re-enable behavior (without switching to full `config.yaml`)

Edit `config.kiosk.yaml`:

| Goal | Setting |
|---|---|
| Base turns on ToF during voice | `voice_profile.freeze_base_during_voice: false` |
| Idle base wandering | `base.wander_enabled: false` to disable again |
| Face track during conversation | `stream.vision_pause_on_audio: false` |
| Debug 3D map + MJPEG | `debug_viz.auto_start: true` or `DEBUG_VIZ=1` |
| Higher face detection rate | Raise `stream.vision_fps`, `camera.main_res`, `camera.detect_res` |
| Faster servos (more CPU) | Raise `servo.loop_hz` and `voice_profile.servo_loop_hz` |
| Bye wave | `bye_wave.enabled: true` |

After config changes, restart the backend:

```bash
# Ctrl+C on launch script, then:
./scripts/launch-kiosk-stack.sh
```

---

## Compare configs at a glance

```bash
# Run with full tuning (heavier — dev machine or Pi without Chromium)
python start_robot.py start

# Run with kiosk tuning (recommended on Pi with UI)
CONFIG_PATH=config.kiosk.yaml python start_robot.py start
```

| File | When to use |
|---|---|
| `config.yaml` | Development, higher vision rates, 80 Hz servos, debug viz auto-start |
| `config.kiosk.yaml` | **Pi demo** — frontend + Chromium + voice on one board |

---

## Related files

| Path | Role |
|---|---|
| `config.kiosk.yaml` | Kiosk tuning values |
| `scripts/launch-kiosk-stack.sh` | Backend + frontend + Chromium (uses kiosk config) |
| `scripts/kiosk.sh` | Fullscreen Chromium → `http://127.0.0.1:3000/` |
| `voice/local_audio_io.py` | Pi mic + AEC |
| `voice/local_speaker.py` | Pi speaker + TTS sink |
| `core/face_tracking.py` | Vision pause during audio |
| `core/base_controller.py` | Base freeze during voice, ToF approach / glance |

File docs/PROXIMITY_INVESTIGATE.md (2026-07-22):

# ToF Proximity + Investigate System

This document describes how the robot reacts when the three VL53L0X time-of-flight (ToF) sensors detect someone approaching. It covers every behavioral case, what each subsystem does, and how the 3D debug map represents the result.

**Entry point:** `start_robot.py`  
**Config:** `config.yaml` → `proximity` and `proximity.investigate`

---

## Quick reference — what happens in each case

| Robot context | ToF zone | Base (chassis) | Head (neck) | Eyes / emotion | Floor map |
|---|---|---|---|---|---|
| **Tracking face or body** | L | No turn — keeps tracking target | Quick glance left (~35° blend × 0.35) | `looking_left_natural` | Orange **M** motion ghost at world bearing |
| **Tracking face or body** | R | No turn | Quick glance right | `looking_right_natural` | Orange **M** ghost |
| **Tracking face or body** | C | No turn | Brief glance (minimal pan offset) | `attentive` | Orange **M** ghost |
| **Wander / idle** | L | Turn left ~35° | After turn: tilt sweep 2.5 s | Normal wander emotion | **M** ghost → fades or upgrades |
| **Wander / idle** | R | Turn right ~35° | After turn: tilt sweep | Normal wander emotion | Same |
| **Wander / idle** | C | No turn | Tilt sweep only (no base step) | Normal wander emotion | Same |
| **After scan — camera sees person** | any | May revisit verified spot in wander | — | — | **M** removed; yellow **P** (face) or blue **P** (body) |
| **After scan — no camera hit** | any | Resume wander | — | — | **M** ghost fades out over 5 s |
| **Wander + verified spot < 5 s old** | — | Small turn toward verified yaw (priority over random wander) | Another tilt scan after turn | — | Uses **P** marker, not **M** |
| **Voice session active (not tracking)** | L / R | No base turn | Head glance (legacy voice path) | Conversation emotion | No investigate FSM |
| **Investigate disabled** | L / R | Turn only | Old `prox_search` hold-center | — | No motion ghosts |

---

## End-to-end pipeline

```
ESP32 firmware (3× VL53L0X via TCA9548A)
        │  serial: PROX L/C/R velocity distance confidence
        ▼
hardware/arduino_servo.py  →  parses PROX lines (non-blocking)
        ▼
core/servo_mixer.py        →  writes prox_* fields to Blackboard
                             (L/R may be mirrored via swap_left_right)
        ├──────────────────────────────────────────┐
        ▼                                          ▼
core/base_controller.py    core/face_tracking.py
  • plans base turns         • records motion ghosts (MotionMemory)
  • starts investigate FSM   • verifies person on camera hit
  • wander revisit           • publishes motion_snapshots
        │                                          │
        ▼                                          ▼
core/servo_loop.py         core/emotion_engine.py
  • tilt scan during         • prox_glance_emotion override
    investigate              during track glance
  • head glance overlay
        │
        ▼
head_debug_viz.py (3D map)
  • orange M{id} motion ghosts (fading)
  • yellow/blue P{id} person memories (existing)
```

All modules share state through **`core/blackboard.py`**.

---

## Sensing layer

### Hardware

- Three VL53L0X sensors: **Left**, **Center**, **Right** on a TCA9548A I²C mux.
- ESP32 firmware streams `PROX` events when approach velocity and confidence thresholds are met.
- `proximity.swap_left_right: true` in config mirrors L/R in Python when physical wiring does not match labels.

### Blackboard fields (written by ServoMixer)

| Field | Meaning |
|---|---|
| `prox_approach_active` | Valid approach event in progress |
| `prox_approach_zone` | `"L"`, `"C"`, or `"R"` |
| `prox_approach_velocity` | mm/s (negative = approaching) |
| `prox_approach_distance` | mm |
| `prox_approach_confidence` | Consecutive confirm frames from firmware |
| `prox_approach_ts` | Timestamp of last PROX event (dedup key) |
| `prox_zone_left/center/right` | Lingering presence (not approach) |
| `prox_post_turn_lockout_ts` | Ignore new reactions until this time |

### Gating — when a PROX event is **ignored**

`BaseController._plan_proximity_step` will not react if any of these are true:

- `proximity.enabled` is false
- `prox_approach_active` is false
- Same `prox_approach_ts` already reacted to (one reaction per event)
- Inside post-turn lockout window
- Within `post_motion_blanking_sec` after any base motion finished
- Within `cooldown_sec` since last prox reaction
- `prox_approach_confidence` < `min_confidence` (default 3)
- More than `max_turns_per_window` turns in `turn_window_sec`

---

## Case 1 — Tracking face or body + ToF approach

**When:** `face_detected` or `body_detected` is true, and `proximity.investigate.enabled` is true.

### Base

- **No base turn.** Tracking target is preserved.
- `_plan_proximity_step` returns no step; calls `_trigger_prox_glance` instead.

### Head (`servo_loop._tick_track`)

- `prox_glance_active` overlay runs alongside normal tracking PID.
- **Toward phase** (~0.8 s): pan blends toward `prox_glance_target_pan`.
  - L: pan offset = `+turn_step_deg × glance_blend_track` (default 35° × 0.35)
  - R: pan offset = negative of that
  - C: no meaningful offset
- **Return phase** (~0.6 s): glance ends; tracking resumes full control.
- While tracking, blend is capped at `glance_blend_track` (weaker peek so track is not disrupted).

### Emotion (`emotion_engine.py`)

- While `prox_glance_active` and `prox_glance_emotion` is set:
  - L → `looking_left_natural`
  - R → `looking_right_natural`
  - C → `attentive`
- Overrides normal surroundings emotion for the glance duration.

### Map (`face_tracking._record_prox_motion`)

- Creates or updates a **motion ghost** in `MotionMemory`.
- World bearing: `base_world_yaw_deg + zone_offset` (L ≈ −35°, C = 0°, R ≈ +35°).
- Published as `motion_snapshots` → 3D viz shows orange pulsing **M{id}** on the floor arc.

---

## Case 2 — Wander / idle + ToF approach from the **left** or **right**

**When:** No face/body track, not in voice-session glance path, zone is L or R.

### Base (`base_controller`)

1. Plans a base step: `±turn_step_deg` (default 35°) toward the zone.
2. Applies neck compensation (`compensation_gain`) so gaze stays roughly forward during turn.
3. Calls `_start_investigate(..., phase="turn")`.
4. Sets post-turn lockout.

### Investigate FSM phases

| Phase | Who advances it | What happens |
|---|---|---|
| `"turn"` | Base motion completes → phase becomes `"scan"` | Head holds pan center + level tilt while base rotates |
| `"scan"` | `servo_loop._tick_prox_investigate` (~2.5 s) | Tilt sweep: center → down (12°) → up (8°) → center |
| `"done"` | Scan timer expires | Investigate cleared; fade signal sent |

### Head during scan

- Pan held at center (body already aimed for L/R).
- Tilt animates over `scan_duration_sec` (default 2.5 s).
- If face or body appears during scan → investigate cleared immediately (verify path runs).

### Map

- Motion ghost recorded at computed world bearing (same as Case 1).
- Outcome depends on camera (Cases 4 and 5 below).

---

## Case 3 — Wander / idle + ToF approach from **center**

**When:** No track, zone is C, investigate enabled.

### Base

- **No base turn.** `_start_investigate(..., phase="scan")` immediately.

### Head

- Goes straight into tilt sweep (same as scan phase in Case 2).

### Map

- Motion ghost at `base_world_yaw_deg` (no lateral offset).

---

## Case 4 — Investigate ends + **camera confirms** person

**When:** During investigate (`phase` is `turn`, `scan`, or `done`) and `face_detected` or `body_detected`.

### Person memory (`lib/person_memory.py`)

- New observation with `source="prox_verify"`.
- **Shorter TTL:** `verified_ttl_sec` (default 5 s), not the normal 20 s person timeout.
- Face: full `observe()` with norm x/y and pan.
- Body only: `observe_at_yaw()` at `prox_investigate_yaw`.

### Motion memory

- Linked ghost marked `verified=True` → removed from viz snapshots.
- Person appears as existing **P{id}** marker (yellow face / blue body).

### Wander priority

- `prox_verified_priority_yaw` published on blackboard.
- In wander mode, `_plan_prox_verified_revisit` runs **before** random wander turns:
  - Only if verified person age < `revisit_max_age_sec` (5 s).
  - Only if current aim is more than `revisit_aim_tolerance_deg` (15°) off target.
  - Plans a small base step, then starts investigate again (`phase="turn"` → scan).
- **Unverified motion ghosts never drive wander turns** (by design).

---

## Case 5 — Investigate ends + **no camera hit**

**When:** Scan timer completes without face/body detection.

### Sequence

1. `servo_loop` sets `prox_investigate_active=False`, `prox_investigate_phase="done"`, `prox_scan_complete_ts=now`.
2. `face_tracking._handle_prox_verify` sees new `prox_scan_complete_ts`.
3. Calls `motion_memory.start_fade(motion_id)` for the linked ghost.

### Map

- Orange **M{id}** remains on floor.
- `freshness` decays from 1 → 0 over `motion_fade_sec` (default 5 s).
- Pulsing ring opacity follows freshness.
- Ghost pruned when freshness hits 0.

---

## Case 6 — Voice session active (not tracking)

**When:** `voice_session_active` and not currently tracking face/body.

- L/R approach triggers a **head glance only** (older voice path).
- Uses `glance_blend` (0.4), not `glance_blend_track`.
- No investigate FSM, no motion ghost requirement from this path alone (ghost still recorded if a separate valid PROX event fires while not gated).

---

## Case 7 — Investigate **disabled**

**When:** `proximity.investigate.enabled: false`.

- L/R wander still gets base turn.
- Legacy `prox_search_active` hold-center behavior instead of tilt sweep.
- No `MotionMemory` / orange ghosts (FaceTracker skips motion memory init).

---

## Memory types

### Motion ghosts (`lib/motion_memory.py`)

Short-lived **unverified** ToF cues. Separate from person memory.

| Field | Purpose |
|---|---|
| `id` | Shown as M{id} on viz |
| `world_yaw_deg` | Floor position on 1.2 m arc |
| `zone` | L / C / R |
| `distance_mm` | Last ToF distance |
| `fade_start_ts` | When 5 s fade began |
| `verified` | True after camera confirm → hidden |

### Person memory (`lib/person_memory.py`)

Camera-anchored people on the floor map.

| Source | TTL | Drives wander? |
|---|-----|---|
| `"camera"` | `person_memory.timeout_sec` (20 s) | Via existing memory follow |
| `"prox_verify"` | `verified_ttl_sec` (5 s) | Yes — `_plan_prox_verified_revisit` |

---

## 3D debug visualization

**File:** `head_debug_viz.py`  
**Data path:** `debug_dashboard.py` → `/api/state`

| Marker | Color | Label | When |
|---|---|---|---|
| Motion ghost | Orange `#f97316` | `M{id}` | Unverified ToF approach; opacity = freshness |
| Person (face) | Yellow | `P{id}` | Camera or prox_verify face |
| Person (body) | Blue | `P{id}` | Camera or prox_verify body |
| ToF beams | Cyan / orange | L/C/R HUD | Live presence + approach |

Legend includes **“ToF motion (fading)”**. Prox HUD shows APPROACH, INVESTIGATE (phase), GLANCING, or clear.

---

## Blackboard investigate fields

| Field | Values | Set by |
|---|---|---|
| `prox_investigate_active` | bool | base_controller, servo_loop, face_tracking |
| `prox_investigate_phase` | `""` \| `"turn"` \| `"scan"` \| `"done"` | base_controller, servo_loop |
| `prox_investigate_zone` | L / C / R | base_controller |
| `prox_investigate_yaw` | degrees | base_controller |
| `prox_investigate_since` | timestamp | base_controller (reset on phase → scan) |
| `prox_investigate_motion_id` | int | face_tracking |
| `prox_verified_priority_yaw` | float \| None | face_tracking |
| `prox_scan_complete_ts` | float | servo_loop (fade trigger) |
| `prox_glance_emotion` | emotion name | base_controller |
| `motion_snapshots` | list[dict] | face_tracking |

---

## Config reference

```yaml
proximity:
  enabled: true
  swap_left_right: true          # mirror L/R if wiring ≠ labels
  min_confidence: 3
  turn_step_deg: 35.0
  cooldown_sec: 5.0
  post_turn_lockout_sec: 2.0
  post_motion_blanking_sec: 1.5
  glance_toward_sec: 0.8
  glance_return_sec: 0.6
  glance_blend: 0.4              # voice-session glance strength

  investigate:
    enabled: true
    motion_fade_sec: 5.0         # M-marker fade duration
    verified_ttl_sec: 5.0        # P-marker from prox_verify
    scan_duration_sec: 2.5
    scan_tilt_down_deg: 12.0
    scan_tilt_up_deg: 8.0
    zone_yaw_deg: 35.0           # L/R bearing offset from body forward
    glance_blend_track: 0.35     # head peek strength while tracking
    revisit_enabled: true
    revisit_max_age_sec: 5.0
    revisit_aim_tolerance_deg: 15.0
```

---

## State diagram

```mermaid
stateDiagram-v2
    direction LR
    ToFTrigger --> ContextCheck
    ContextCheck --> HeadGlance: tracking
    ContextCheck --> Investigate: wander_idle
    HeadGlance --> MotionGhost
    Investigate --> BaseTurn: zone_L_or_R
    Investigate --> TiltScan: zone_C
    BaseTurn --> TiltScan
    TiltScan --> CameraCheck
    CameraCheck --> VerifiedPerson: face_or_body
    CameraCheck --> FadeGhost: no_detection
    VerifiedPerson --> WanderPriority
    FadeGhost --> MotionGhost
```

---

## Priority order in wander mode (base_controller)

When `servo_mode == "wander"` and base is idle:

1. **Prox verified revisit** — aim at `prox_verified_priority_yaw` if fresh
2. Wander follow (existing)
3. Sustained hold follow
4. **New prox approach** — turn + investigate or center scan
5. Random wander turns (lowest)

---

## Key source files

| File | Role |
|---|---|
| `hardware/arduino_servo.py` | PROX serial parsing, ToF mute during base motion |
| `core/servo_mixer.py` | Blackboard prox fields, L/R swap |
| `core/base_controller.py` | Context routing, turns, revisit, investigate start |
| `core/servo_loop.py` | Glance overlay, tilt scan FSM |
| `core/face_tracking.py` | Motion ghosts, camera verify, snapshots |
| `core/emotion_engine.py` | Glance emotion override |
| `lib/motion_memory.py` | ToF ghost store + fade |
| `lib/person_memory.py` | Person store + `prox_verify` TTL |
| `lib/prox_investigate.py` | Zone → world yaw, glance emotion helpers |
| `head_debug_viz.py` | M and P floor markers, prox HUD |
| `core/debug_dashboard.py` | API snapshot for viz |

---

## Manual test checklist

1. **Wander + R approach** — base turns right → tilt sweep → no face → orange M fades over 5 s  
2. **Wander + approach + person in frame** — M upgrades to P; wander revisits within 5 s  
3. **Track + L approach** — no base move; head glances left; emotion shifts; track unchanged  
4. **Center approach idle** — no base turn; tilt sweep only  
5. **3D viz** — M icons on correct side; verified persons use P markers  

---

## Out of scope (current build)

- Firmware zone label changes (use `swap_left_right` in config instead)
- Patrolling all motion ghosts — only **verified** spots get wander revisit
- Multi-ghost queue / patrol route

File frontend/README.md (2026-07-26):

# NEma Campus Kiosk Frontend

Next.js 15 touchscreen application for the **NEma Raspberry Pi 4 Kiosk System**.

## Features
- **Local NLU Voice Interface**: Browser VAD + WebSocket communication to local Python ChromaDB NLU server (`ws://localhost:8765/ws/voice`).
- **Interactive Campus 3D Map**: Map navigation, room search, and pathfinding visualization.
- **Event Poster Showcase**: Touchscreen poster gallery, carousel, and automatic AI-extracted event detail modals.
- **Admin Upload Portal**: Live poster image uploading and status dashboard (`/upload-portal`).

## Getting Started

### Development Mode (with hot reload)
```bash
pnpm install
pnpm dev
```
Open [http://localhost:3000](http://localhost:3000) in your browser.

### Production Build & Run (Raspberry Pi 4)
```bash
pnpm build
pnpm start
```

## Environment Configuration (`.env.local`)
Create `.env.local` in the `frontend` directory:
```ini
NEXT_PUBLIC_LOCAL_SPEAKER=true
NEXT_PUBLIC_NLU_MODE=true
NEXT_PUBLIC_NLU_SERVER_URL=ws://127.0.0.1:8765/ws/voice
KIOSK_API_URL=http://127.0.0.1:8080
```

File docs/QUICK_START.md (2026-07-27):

# Voice Agent V5 — Raspberry Pi Kiosk Stack

An end-to-end autonomous Raspberry Pi 4 kiosk stack featuring **YuNet face tracking**, **servos & TFT eyes**, **browser VAD + local ChromaDB NLU voice pipeline**, **48kHz audio sync**, and a **Next.js interactive touchscreen kiosk UI**.

---

## 📋 Table of Contents
1. [Fresh Raspberry Pi Setup (From Scratch)](#1-fresh-raspberry-pi-setup-from-scratch)
2. [Hardware & Boot Configuration (`config.txt`)](#2-hardware--boot-configuration-configtxt)
3. [Audio Optimization & USB Sound Card Setup](#3-audio-optimization--usb-sound-card-setup)
4. [Environment & API Keys (`.env`)](#4-environment--api-keys-env)
5. [Poster Management & NLU Intent Database](#5-poster-management--nlu-intent-database)
6. [Frontend Build & Setup](#6-frontend-build--setup)
7. [Starting the System](#7-starting-the-system)
8. [Project Architecture & Ports](#8-project-architecture--ports)
9. [Troubleshooting & Maintenance](#9-troubleshooting--maintenance)

---

## 1. Fresh Raspberry Pi Setup (From Scratch)

If you are setting up a brand-new Raspberry Pi 4 (Raspberry Pi OS 64-bit Bookworm), run the following system package installation first:

### Step 1: Install System Dependencies (Apt)
```bash
sudo apt update && sudo apt install -y \
  git \
  python3-pip \
  python3-venv \
  python3-picamera2 \
  libportaudio2 \
  alsa-utils \
  pipewire \
  pipewire-alsa \
  ffmpeg \
  i2c-tools \
  unclutter \
  mesa-utils
```

### Step 2: Install Node.js 20+ & pnpm
```bash
curl -fsSL https://deb.nodesource.com/setup_20.x | sudo -E bash -
sudo apt install -y nodejs
sudo npm install -g pnpm
```

---

## 2. Hardware & Boot Configuration (`config.txt` & `cmdline.txt`)

To ensure smooth 64-bit performance, hardware 3D WebGL rendering, GPU memory allocation, and correct 10.1" kiosk display resolution, set up `/boot/firmware/config.txt` and `/boot/firmware/cmdline.txt`.

### Complete `/boot/firmware/config.txt` (Copy & Paste):
```ini
# --- Hardware Interfaces ---
dtparam=i2c_arm=on
dtparam=spi=on
dtparam=i2c_vc=on

# Enables the second SPI bus (SPI1) for pins D21, D20, D19
dtoverlay=spi1-3cs
dtparam=audio=on

# --- Hardware Detection ---
camera_auto_detect=1
auto_initramfs=1

# --- Video Driver & Memory Settings ---
gpu_mem=256
dtoverlay=cma,cma-256
max_framebuffers=2

# Run in 64-bit mode
arm_64bit=1
disable_overscan=1
arm_boost=1

[all]
# ==============================================================================
# DISPLAY PROFILE 1: 10.1 Inch Kiosk Display (1024x600 Custom Timings) [ACTIVE]
# ==============================================================================
display_auto_detect=0
disable_fw_kms_setup=1
#dtoverlay=vc4-kms-v3d
max_usb_current=1
hdmi_force_hotplug=1
config_hdmi_boost=7
hdmi_group=2
hdmi_mode=87
hdmi_drive=2
hdmi_force_edid_audio=1
display_rotate=0
hdmi_timings=1024 1 50 18 50 600 1 15 3 15 0 0 0 60 0 40000000 3

# ==============================================================================
# DISPLAY PROFILE 2: Standard External Monitor / TV (Auto-Detect) [INACTIVE]
# ==============================================================================
#display_auto_detect=1
#disable_fw_kms_setup=0
#dtoverlay=vc4-kms-v3d
#hdmi_force_hotplug=1
#config_hdmi_boost=4

# --- ACTIVE OVERCLOCK (2.1 GHz) ---
over_voltage=6
arm_freq=2100
gpu_freq=750

consoleblank=0
```

### Complete `/boot/firmware/cmdline.txt` (Copy & Paste):
```text
console=serial0,115200 console=tty1 root=PARTUUID=e9d8c97a-02 rootfstype=ext4 fsck.repair=yes rootwait quiet splash plymouth.ignore-serial-consoles cfg80211.ieee80211_regdom=LK
```

> ⚠️ **Important**: Ensure `video=HDMI-A-1:...` is **NOT** present in `/boot/firmware/cmdline.txt` so it does not override or fight the 1024x600 display timings set in `config.txt`.
> 
> Reboot after saving both files:
> ```bash
> sudo reboot
> ```

---

## 3. Audio Optimization & USB Sound Card Setup

To prevent Pi CPU micro-stutters during speech playback, the voice pipeline forces **uncompressed 48000Hz WAV audio** across PipeWire, Web Audio, and ALSA.

### Configure ALSA Defaults for USB Sound Card:
If using an external USB Audio Adapter (recommended to bypass CPU-bound PWM audio resampling):
```bash
cd voice-agentv5
bash scripts/setup_alsa.sh
```
This automatically detects your USB Audio Adapter (e.g. `card 3`) and writes `~/.asoundrc` for zero-resampling 48kHz output.

---

## 4. Environment & API Keys (`.env`)

Clone the repository and install Python dependencies:

```bash
git clone https://github.com/makiladamsuka/voice-agentv5.git
cd voice-agentv5

# Create venv with system site-packages (required for picamera2)
python3 -m venv --system-site-packages venv
source venv/bin/activate
pip install -r requirements.txt
```

Create a `.env` file in the root project directory:

```bash
cp .env.example .env 2>/dev/null || touch .env
nano .env
```

### Required `.env` Keys:
```ini
DEEPGRAM_API_KEY=your_deepgram_api_key_here
OPENROUTER_API_KEY=your_openrouter_api_key_here
GROQ_API_KEY=your_groq_api_key_here
```

---

## 5. Poster Management & NLU Intent Database

Because poster images, generated vector databases (`voice/event_db/`), and synthesized WAV audio caches (`assets/audio_cache/`) are runtime-generated and ignored by Git, you must compile the intent database when setting up a new Pi.

### How to Add Event Posters:
1. Place poster image files (`.jpg`, `.png`, `.webp`) in the corresponding asset directories:
   - `assets/events/` (Campus events)
   - `assets/competitions/` (Undergraduate hackathons/contests)
   - `assets/posts/` (General announcements)
2. *Or* upload them at runtime via the Admin Upload Portal in the kiosk UI at `http://localhost:3000/upload-portal`.

### How to Build & Manage the Event Vector Database:
Run the intent compiler script:
```bash
python voice/compiler/intent_compiler.py
```

### What `intent_compiler.py` Does:
1. **AI Extraction**: Uses OpenRouter/Groq to parse title, date, time, location, and description from poster images into `voice/event_db/extracted_events.json`.
2. **Utterance Generation**: Generates standard user questions for each event poster into `voice/event_db/compiled_intents.json`.
3. **TTS Speech Synthesis**: Synthesizes 48kHz uncompressed `.wav` audio files into `assets/audio_cache/` so fallback and intent answers play instantly with zero live TTS latency.
4. **ChromaDB Indexing**: Indexes all intents into the local ChromaDB vector database (`voice/event_db/`).

---

## 6. Frontend Build & Setup

Install Node.js packages and build the production Next.js kiosk application:

```bash
cd frontend
pnpm install
pnpm build
cd ..
```

---

## 7. Starting the System

### Option A: All-In-One Kiosk Stack (Recommended for Kiosks)
Runs the Python backend, Next.js frontend, and fullscreen Chromium kiosk browser concurrently in isolated CPU cores:

```bash
./scripts/launch-kiosk-stack.sh
```

### Option B: Manual Multi-Terminal Startup

#### Terminal 1 — Python Robot & NLU Server (:8080 & :8765):
```bash
source venv/bin/activate
CONFIG_PATH=config.kiosk.yaml python start_robot.py
```

#### Terminal 2 — Frontend Kiosk Web Server (:3000):
```bash
cd frontend
pnpm start
```

#### Terminal 3 — Fullscreen Kiosk Browser:
```bash
./scripts/kiosk.sh
```

---

## 8. Project Architecture & Ports

| Port | Service | Description |
|---|---|---|
| **3000** | Next.js Kiosk UI | Touchscreen user interface & Browser VAD mic capture |
| **8765** | NLU WebSocket | Local ChromaDB intent matcher & voice state manager |
| **8080** | Python MediaServer | Serves static assets, poster uploads, map graph APIs |
| **8082** | Debug Dashboard | Optional 3D ToF map + MJPEG camera stream (`DEBUG_VIZ=1`) |

### Directory Overview:
```
voice-agentv5/
├── start_robot.py             # Main entry point (hardware, vision, voice, APIs)
├── config.kiosk.yaml          # Optimized Pi 4 kiosk configuration
├── requirements.txt           # Python package dependencies
├── assets/
│   ├── events/                # Event poster image files
│   ├── competitions/          # Competition poster image files
│   ├── posts/                 # Announcement poster image files
│   └── audio_cache/           # Pre-synthesized 48kHz WAV audio files (Generated)
├── voice/
│   ├── nlu_server.py          # FastAPI/Starlette NLU WebSocket server
│   ├── event_database.py      # ChromaDB event vector database manager
│   ├── event_indexer.py       # AI Vision poster metadata extractor
│   ├── compiler/
│   │   └── intent_compiler.py # Builds compiled_intents.json & synthesizes audio
│   └── event_db/              # Local ChromaDB index & JSON manifests (Generated)
├── frontend/                  # Next.js kiosk touchscreen interface
└── scripts/
    ├── launch-kiosk-stack.sh  # Master launch script (Backend + Frontend + Browser)
    ├── setup_alsa.sh          # USB audio card ALSA setup
    ├── kiosk.sh               # Fullscreen Chromium launcher
    └── refresh-kiosk.sh       # Reload kiosk window after code edits
```

---

## 9. Troubleshooting & Maintenance

### Reload Kiosk UI After Code Edits:
```bash
./scripts/refresh-kiosk.sh
```

### Re-index Posters Manually:
If you add new posters and want to rebuild the vector database immediately:
```bash
python voice/compiler/intent_compiler.py
```

### Measure System Resources (CPU/RAM/Temp):
```bash
./scripts/measure_resources.sh 60 1 start_robot.py
```

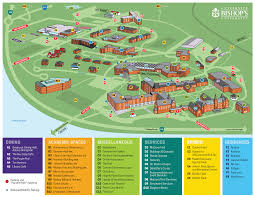
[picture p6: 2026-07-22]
assets/maps/ds_lab.jpg

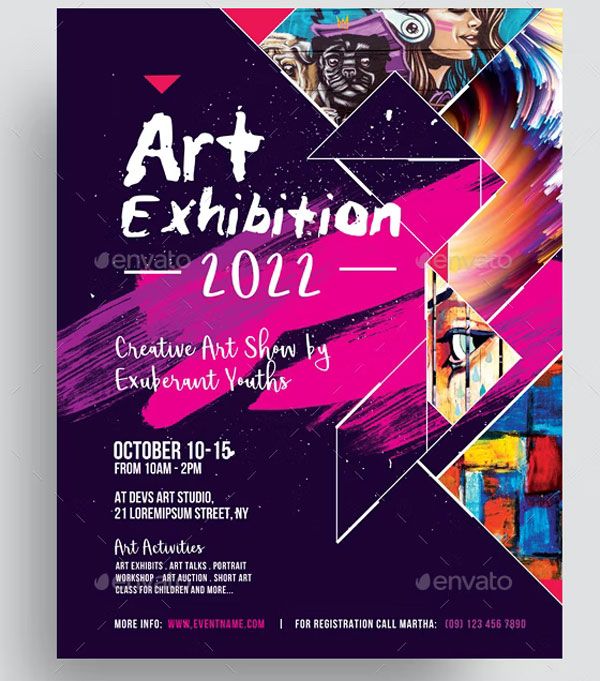
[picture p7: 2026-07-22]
assets/events/art-exhibition.jpg

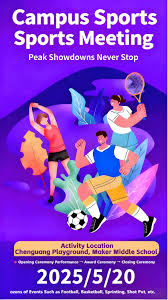
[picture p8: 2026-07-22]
assets/events/freshers-sportmeet.jpg

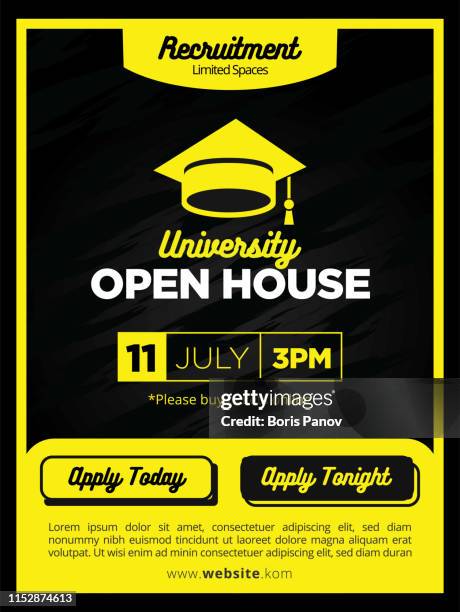
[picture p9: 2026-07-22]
assets/events/openhouse.jpg

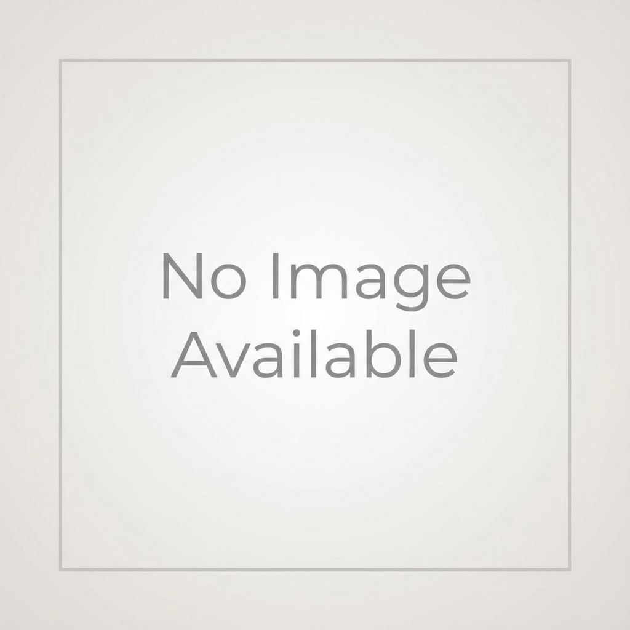
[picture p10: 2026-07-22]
assets/fallback/no_image_found.png

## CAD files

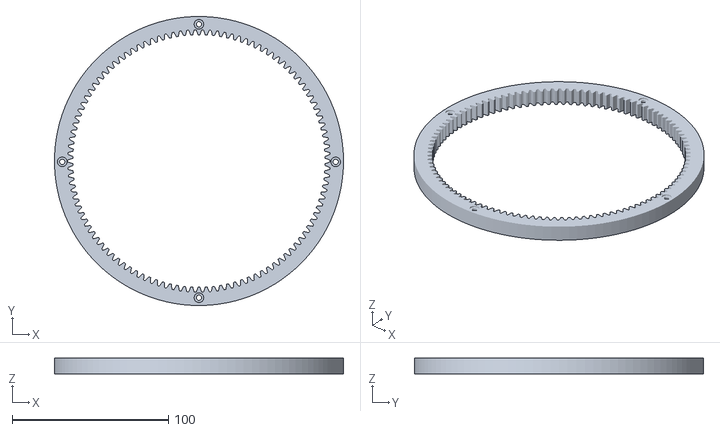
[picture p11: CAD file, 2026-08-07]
hardware/3d_models/stl_parts/110 teeth.stl
185.0 x 185.0 x 10.0

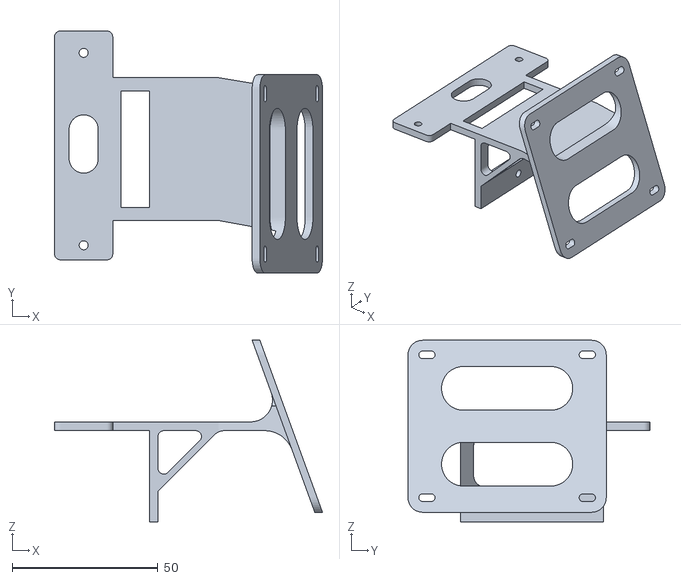
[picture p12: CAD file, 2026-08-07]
hardware/3d_models/stl_parts/displayhol.stl
91.9 x 83.0 x 62.2

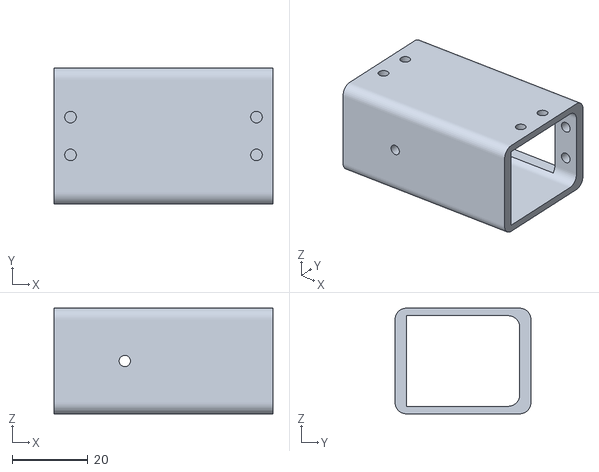
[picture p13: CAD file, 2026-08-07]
hardware/3d_models/stl_parts/headmounthigh.stl
58.0 x 36.0 x 28.0

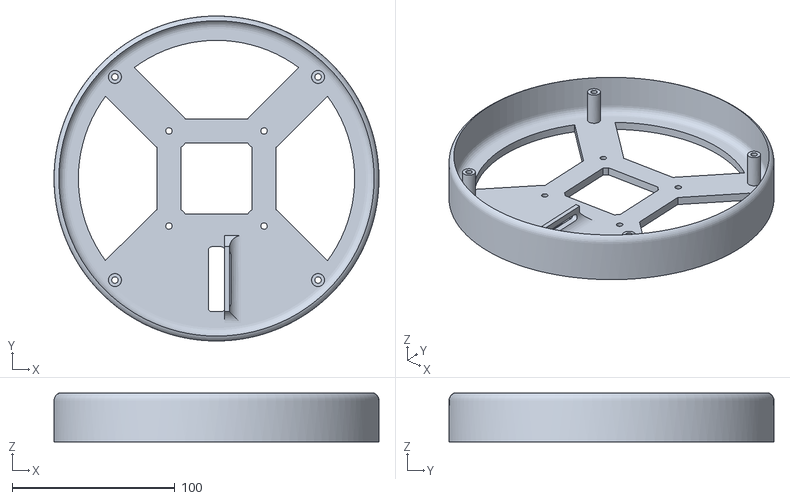
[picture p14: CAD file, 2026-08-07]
hardware/3d_models/stl_parts/topBase.stl
200.0 x 200.0 x 30.0

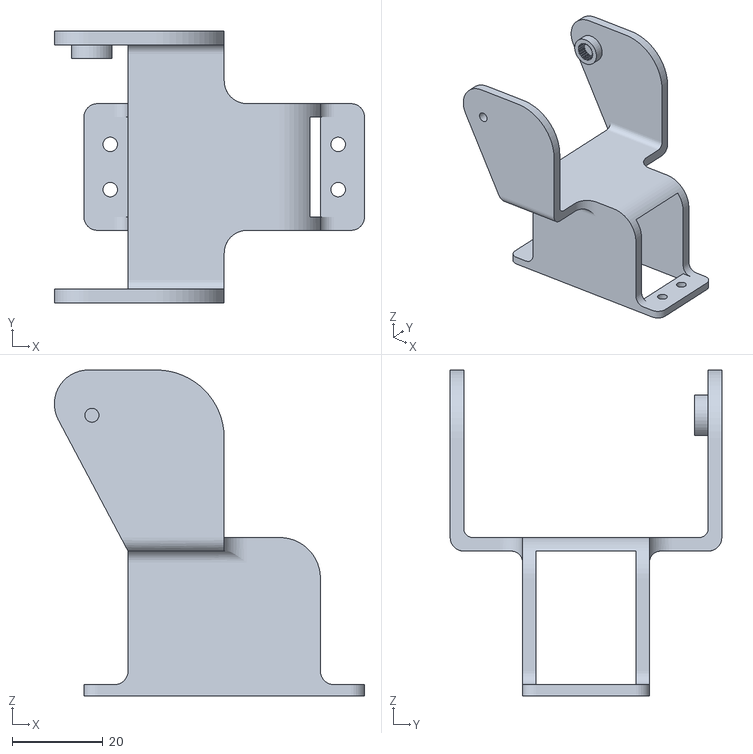
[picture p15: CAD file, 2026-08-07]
hardware/3d_models/stl_parts/headmountlow.stl
68.5 x 60.0 x 72.0

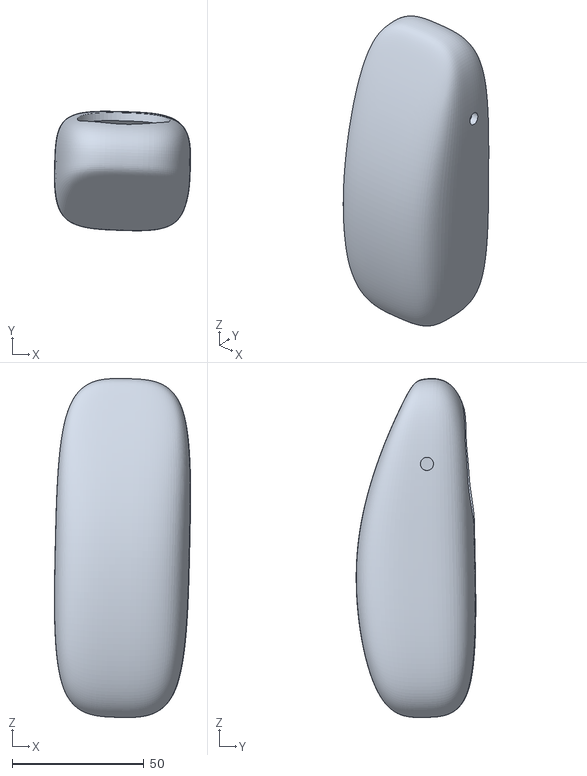
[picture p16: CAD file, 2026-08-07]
hardware/3d_models/stl_parts/RightArm.stl
51.6 x 45.4 x 128.6

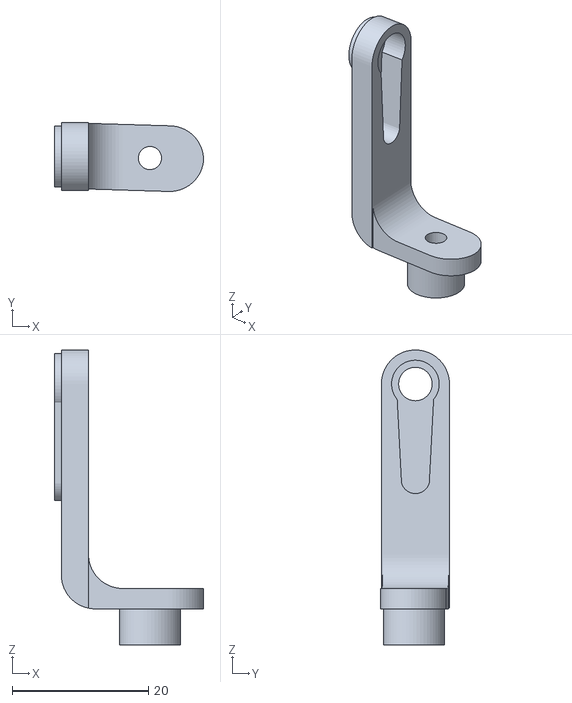
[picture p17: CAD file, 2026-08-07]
hardware/3d_models/stl_parts/shoulderbracket.stl
21.9 x 10.1 x 43.3

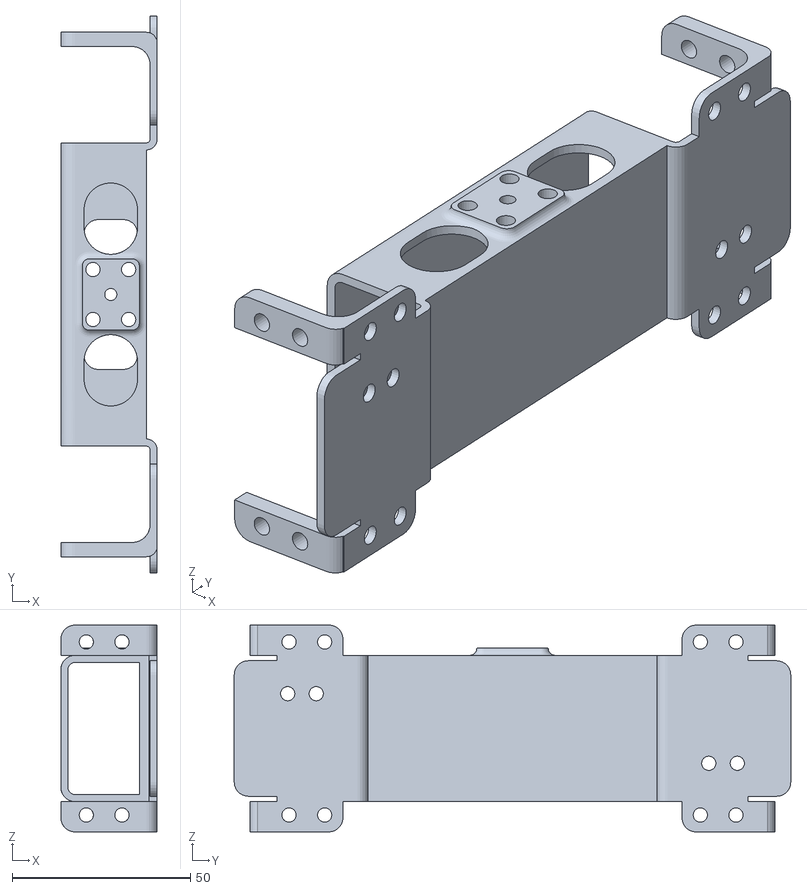
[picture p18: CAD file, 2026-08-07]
hardware/3d_models/stl_parts/Arm Base.stl
27.0 x 156.0 x 58.0

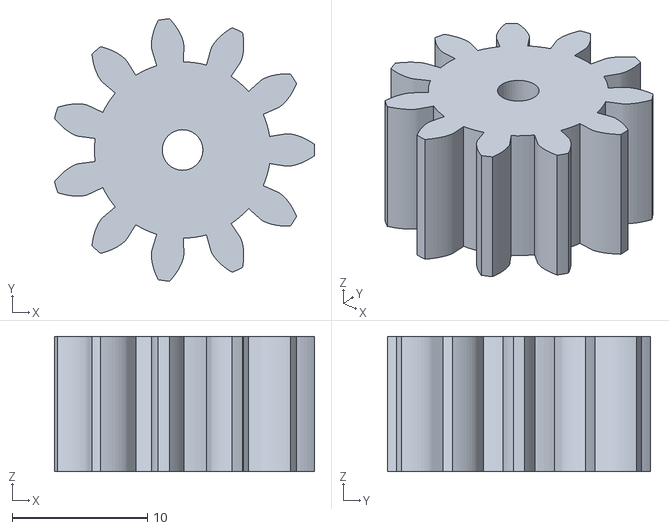
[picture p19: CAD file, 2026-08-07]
hardware/3d_models/stl_parts/Spur Gear 11 teeth.stl
19.2 x 19.4 x 10.0

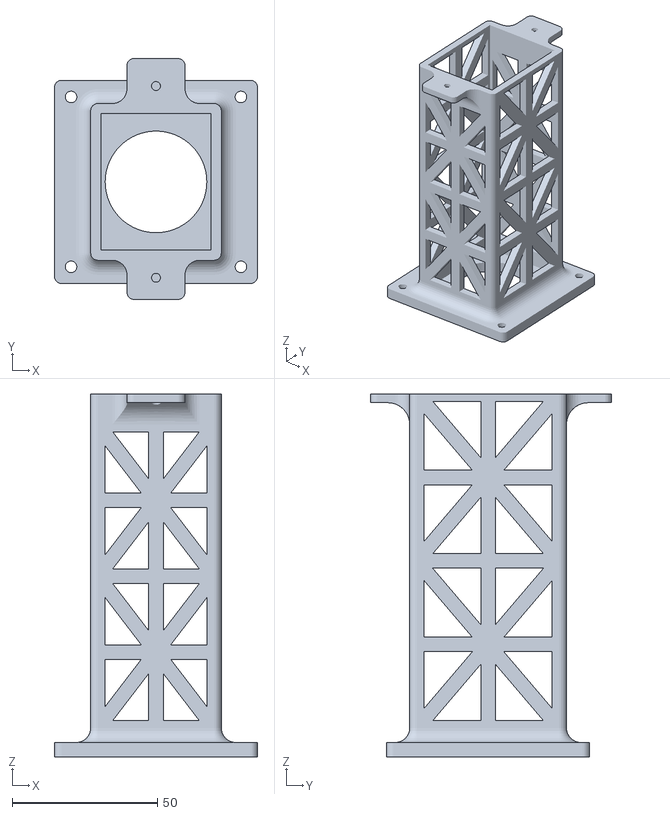
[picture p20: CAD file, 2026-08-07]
hardware/3d_models/stl_parts/spine.stl
70.0 x 83.0 x 125.0

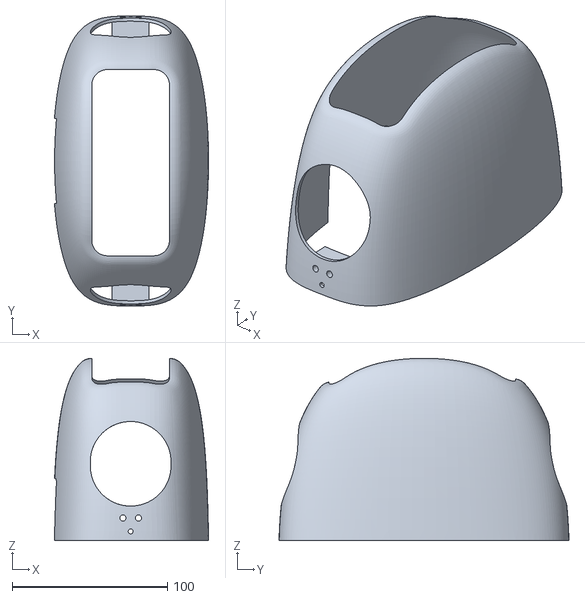
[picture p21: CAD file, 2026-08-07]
hardware/3d_models/stl_parts/upperbody.stl
99.3 x 186.9 x 117.5

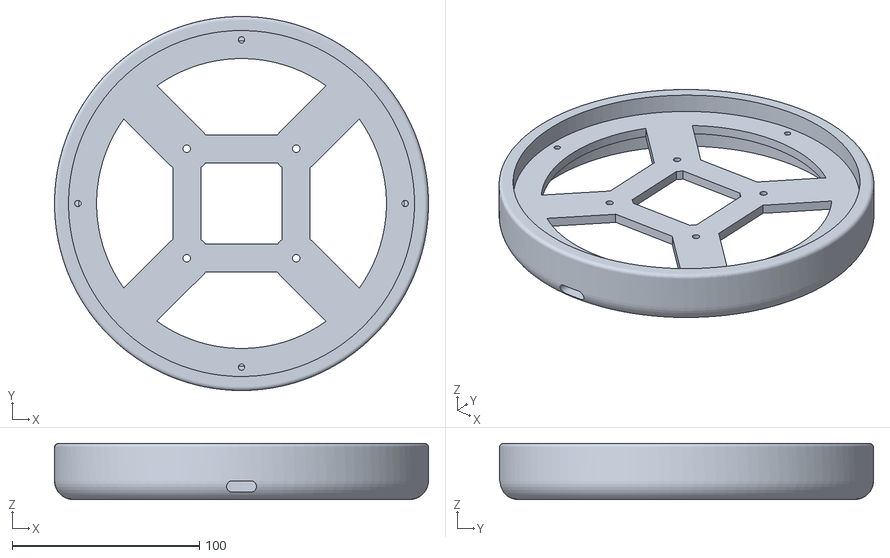
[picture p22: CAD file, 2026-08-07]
hardware/3d_models/stl_parts/bottomBase.stl
200.0 x 200.0 x 30.0

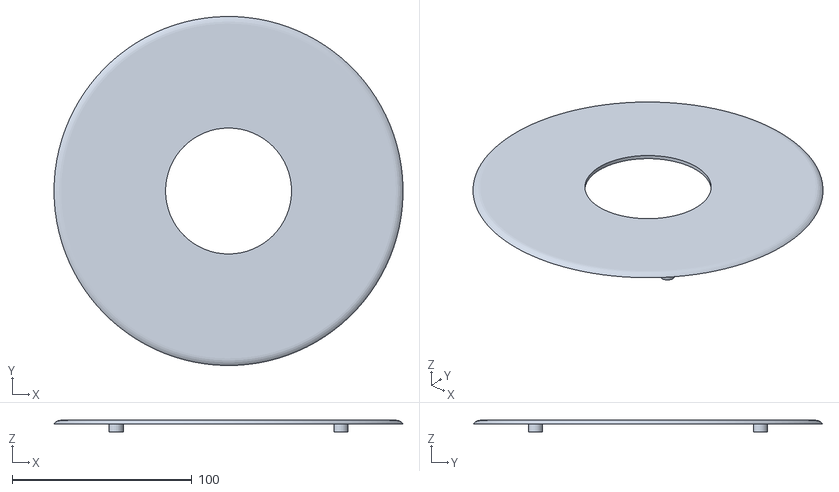
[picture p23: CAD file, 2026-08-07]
hardware/3d_models/stl_parts/basetoplid.stl
194.0 x 194.0 x 6.50

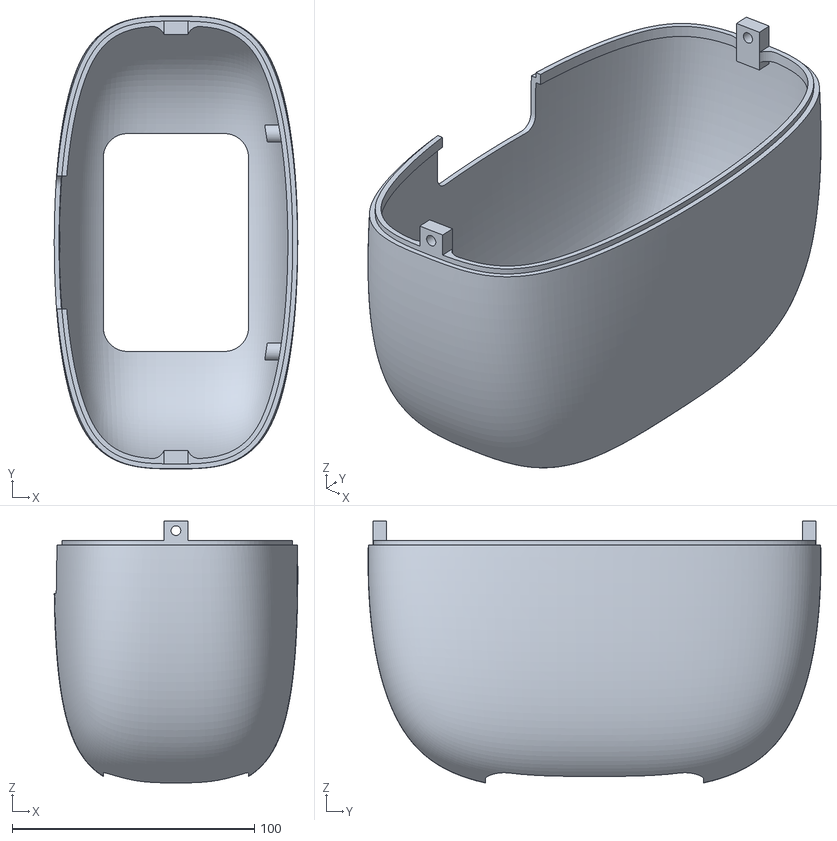
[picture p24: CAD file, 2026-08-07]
hardware/3d_models/stl_parts/lowerbody.stl
100.6 x 187.0 x 108.2

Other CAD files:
hardware/3d_models/stl_parts/HeadServoMount.stl

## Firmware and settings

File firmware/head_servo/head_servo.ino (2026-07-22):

/*
 * Voice Agent V5 ESP32 firmware.
 *
 * Head: PCA9685 @ 0x40 on ESP32 SDA=21 / SCL=22, ch4 pan / ch5 tilt.
 * Base: GPIO35/34 encoder, GPIO25 PWM, GPIO26/27 -> TB6612FNG -> N20 motor.
 *
 * Protocol:
 *   H              -> READY
 *   P80.0 T110.0  -> set head pan/tilt
 *   B+2.0 / B-2.0 -> relative base degrees
 *   B0.0          -> absolute base degrees from zero
 *   J+80 M300     -> open-loop base jog PWM for milliseconds
 *   C1.222        -> set counts per base degree
 *   E-1 / E1      -> encoder sign (+deg command maps to sign*cpd counts)
 *   Z              -> zero base encoder reference
 *   L / R          -> spin base left / right (until X)
 *   X              -> stop base motor (spin, jog, or encoder move)
 *   RL             -> restore pan/tilt limits from firmware defaults
 *   U              -> unlock pan/tilt to 0-180 (manual limit finding)
 *   S              -> bench sweep
 */

#include <Wire.h>
#include <Adafruit_PWMServoDriver.h>
#include <string.h>

const int I2C_SDA_PIN = 21;
const int I2C_SCL_PIN = 22;
const int LED_PIN = 2;

const uint8_t PAN_CH = 4;
const uint8_t TILT_CH = 5;
const float PAN_MIN = 25.0f;
const float PAN_MAX = 150.0f;
const float TILT_MIN = 75.0f;
const float TILT_MAX = 150.0f;
const float PAN_CENTER = 100.0f;
const float TILT_CENTER = 110.0f;
// Runtime limits (writable via U/R for manual limit finding).
float panLimitMin = PAN_MIN;
float panLimitMax = PAN_MAX;
float tiltLimitMin = TILT_MIN;
float tiltLimitMax = TILT_MAX;
const int PULSE_MIN_US = 450;
const int PULSE_MAX_US = 2600;

const int ENC_A_PIN = 35;
const int ENC_B_PIN = 34;
const int MOTOR_PWM_PIN = 25;
const int MOTOR_AIN1_PIN = 26;
const int MOTOR_AIN2_PIN = 27;

const int LINE_BUF_SIZE = 96;
const int ENCODER_TOLERANCE = 35;
const int COARSE_ERR_COUNTS = 48;
const int COARSE_PWM = 150;
const int FINE_MIN_PWM = 82;
const int PWM_MAX = 150;
const int SPIN_PWM = 75;  // lower = gentler open-loop L/R spins from Pi
const unsigned long STALL_MS = 4000;
const int MOTOR_DIR_SIGN = -1;
const int STALL_MIN_PROGRESS = 1;
const unsigned long MOVE_TIMEOUT_MS = 12000;
const float FINE_KP = 1.8f;
const float FINE_PWM_PER_COUNT = 4.0f;
const float MAX_ABS_BASE_DEG = 124.0f;   // Hard safety envelope from startup zero (120 + margin).
const float ABS_LIMIT_MARGIN_DEG = 4.0f; // Allow tiny transient/noise before fault.
const float OVERSHOOT_ALLOW_RATIO = 0.35f;
const long OVERSHOOT_ALLOW_MIN_COUNTS = 140;
const int OVERSHOOT_CONFIRM_CYCLES = 3;
const unsigned long MOVE_KICK_MS = 260;
const int MOVE_KICK_PWM = 150;
const unsigned long JOG_MAX_MS = 3000;

const int LEDC_FREQ_HZ = 20000;
const int LEDC_RES_BITS = 8;
const int LEDC_PWM_CHANNEL = 0;

Adafruit_PWMServoDriver pwm(0x40);
portMUX_TYPE encoderMux = portMUX_INITIALIZER_UNLOCKED;

char lineBuffer[LINE_BUF_SIZE];
uint8_t lineLen = 0;
float panAngle = PAN_CENTER;
float tiltAngle = TILT_CENTER;
bool pcaReady = false;

volatile long encoderCount = 0;
uint8_t encLastState = 0;
long zeroOffset = 0;
long moveTargetCount = 0;
long moveStartCount = 0;
bool baseBusy = false;
bool moveActive = false;
bool jogActive = false;
unsigned long jogEndMs = 0;
unsigned long moveStartMs = 0;
unsigned long lastProgressMs = 0;
long lastProgressCount = 0;
long lastErrorAbs = 0;
long moveMaxTravelCounts = 0;
int overshootCycles = 0;
float ackBaseDeg = 0.0f;
bool pendingBaseAck = false;
int spinPwm = 0;
float countsPerBaseDeg = 1.0f;
float encoderSign = 1.0f;

const int8_t ENC_QUAD_TABLE[16] = {
  0, 1, -1, 0,
  -1, 0, 0, 1,
  1, 0, 0, -1,
  0, -1, 1, 0
};

float clampf(float v, float lo, float hi) {
  if (v < lo) return lo;
  if (v > hi) return hi;
  return v;
}

int mapAngleToUs(float deg, float degMin, float degMax) {
  float t = (deg - degMin) / (degMax - degMin);
  t = clampf(t, 0.0f, 1.0f);
  return PULSE_MIN_US + (int)(t * (float)(PULSE_MAX_US - PULSE_MIN_US));
}

void setServoPulseUs(uint8_t ch, int pulseUs) {
  pulseUs = constrain(pulseUs, PULSE_MIN_US, PULSE_MAX_US);
  uint32_t tick = ((uint32_t)pulseUs * 4096UL) / 20000UL;
  if (tick >= 4096) tick = 4095;
  pwm.setPWM(ch, 0, tick);
}

void serviceEncoder() {
  uint8_t a = digitalRead(ENC_A_PIN) & 1;
  uint8_t b = digitalRead(ENC_B_PIN) & 1;
  uint8_t state = (a << 1) | b;
  if (state == encLastState) return;
  uint8_t idx = (encLastState << 2) | state;
  int8_t delta = ENC_QUAD_TABLE[idx];
  if (delta != 0) {
    encoderCount += delta;
    encLastState = state;
  }
}

void serviceEncoderLocked() {
  portENTER_CRITICAL(&encoderMux);
  serviceEncoder();
  portEXIT_CRITICAL(&encoderMux);
}

void syncEncoderState() {
  uint8_t a = digitalRead(ENC_A_PIN) & 1;
  uint8_t b = digitalRead(ENC_B_PIN) & 1;
  encLastState = (a << 1) | b;
}

long readEncoderCount() {
  portENTER_CRITICAL(&encoderMux);
  long v = encoderCount;
  portEXIT_CRITICAL(&encoderMux);
  return v;
}

float countsToDeg(long counts) {
  if (countsPerBaseDeg < 0.05f || encoderSign == 0.0f) return 0.0f;
  return (float)(counts - zeroOffset) / (countsPerBaseDeg * encoderSign);
}

long degToCounts(float deg) {
  return zeroOffset + (long)(deg * countsPerBaseDeg * encoderSign);
}

bool setCountsPerBaseDeg(float cpd) {
  if (cpd < 0.05f || cpd > 200.0f) return false;
  countsPerBaseDeg = cpd;
  return true;
}

bool setEncoderSign(float sign) {
  if (sign < 0.0f) {
    encoderSign = -1.0f;
  } else if (sign > 0.0f) {
    encoderSign = 1.0f;
  } else {
    return false;
  }
  return true;
}

void motorPwmWrite(int magnitude) {
  magnitude = constrain(magnitude, 0, PWM_MAX);
  int duty = (magnitude * 255) / PWM_MAX;
  ledcWrite(LEDC_PWM_CHANNEL, duty);
}

void motorStop() {
  ledcWrite(LEDC_PWM_CHANNEL, 0);
  digitalWrite(MOTOR_AIN1_PIN, LOW);
  digitalWrite(MOTOR_AIN2_PIN, LOW);
}

void motorDrive(int pwm) {
  pwm = constrain(pwm * MOTOR_DIR_SIGN, -PWM_MAX, PWM_MAX);
  if (pwm == 0) {
    motorStop();
    return;
  }
  if (pwm > 0) {
    digitalWrite(MOTOR_AIN1_PIN, LOW);
    digitalWrite(MOTOR_AIN2_PIN, HIGH);
    motorPwmWrite(pwm);
  } else {
    digitalWrite(MOTOR_AIN1_PIN, HIGH);
    digitalWrite(MOTOR_AIN2_PIN, LOW);
    motorPwmWrite(-pwm);
  }
}

void stopBaseMotion() {
  moveActive = false;
  jogActive = false;
  spinPwm = 0;
  baseBusy = false;
  motorStop();
}

void startBaseSpin(int pwm) {
  moveActive = false;
  jogActive = false;
  pendingBaseAck = false;
  spinPwm = constrain(pwm, -SPIN_PWM, SPIN_PWM);
  baseBusy = spinPwm != 0;
  if (spinPwm != 0) {
    motorDrive(spinPwm);
  } else {
    motorStop();
  }
}

void startBaseSpinLeft() {
  startBaseSpin(-SPIN_PWM);
}

void startBaseSpinRight() {
  startBaseSpin(SPIN_PWM);
}

void printServoAck() {
  Serial.print(F("OK P"));
  Serial.print((int)round(panAngle));
  Serial.print(F(" T"));
  Serial.println((int)round(tiltAngle));
}

void printBaseAck(float deg) {
  Serial.print(F("OK B"));
  Serial.println(deg, 1);
}

void printBaseBusy() {
  Serial.println(F("ERR B busy"));
}

void writeAngles(float pan, float tilt, bool emitAck) {
  panAngle = clampf(pan, panLimitMin, panLimitMax);
  tiltAngle = clampf(tilt, tiltLimitMin, tiltLimitMax);
  if (!pcaReady) {
    if (emitAck) Serial.println(F("ERR PCA9685"));
    return;
  }
  
  // Standard 0-180 degree mapping
  setServoPulseUs(PAN_CH, mapAngleToUs(panAngle, 0.0f, 180.0f));
  setServoPulseUs(TILT_CH, mapAngleToUs(tiltAngle, 0.0f, 180.0f));
  digitalWrite(LED_PIN, HIGH);
  digitalWrite(LED_PIN, LOW);
  if (emitAck) printServoAck();
}

bool startBaseMoveToCount(long targetCount, float ackDeg) {
  if (baseBusy) {
    printBaseBusy();
    return false;
  }
  float targetDeg = countsToDeg(targetCount);
  if (fabs(targetDeg) > MAX_ABS_BASE_DEG) {
    Serial.println(F("ERR B limit"));
    return false;
  }
  moveTargetCount = targetCount;
  ackBaseDeg = ackDeg;
  moveStartCount = readEncoderCount();
  lastProgressCount = moveStartCount;
  lastErrorAbs = labs(targetCount - moveStartCount);
  moveMaxTravelCounts = lastErrorAbs + ENCODER_TOLERANCE * 3;
  moveActive = true;
  baseBusy = true;
  moveStartMs = millis();
  lastProgressMs = moveStartMs;
  overshootCycles = 0;
  return true;
}

bool startBaseRelativeDeg(float deltaDeg) {
  long pos = readEncoderCount();
  long deltaCounts = (long)(deltaDeg * countsPerBaseDeg * encoderSign);
  const long MIN_MOVE_COUNTS = 30;
  if (deltaCounts != 0 && labs(deltaCounts) < MIN_MOVE_COUNTS) {
    deltaCounts = (deltaCounts > 0 ? MIN_MOVE_COUNTS : -MIN_MOVE_COUNTS);
  }
  return startBaseMoveToCount(pos + deltaCounts, deltaDeg);
}

bool startBaseJog(int pwm, unsigned long durationMs) {
  if (baseBusy) {
    printBaseBusy();
    return false;
  }
  pwm = constrain(pwm, -PWM_MAX, PWM_MAX);
  durationMs = constrain(durationMs, 1UL, JOG_MAX_MS);
  if (pwm == 0) {
    Serial.println(F("ERR J zero"));
    return false;
  }
  jogActive = true;
  baseBusy = true;
  jogEndMs = millis() + durationMs;
  motorDrive(pwm);
  Serial.println(F("OK J"));
  return true;
}

bool startBaseAbsoluteDeg(float deg) {
  return startBaseMoveToCount(degToCounts(deg), deg);
}

void zeroBaseReference() {
  if (baseBusy) {
    printBaseBusy();
    return;
  }
  portENTER_CRITICAL(&encoderMux);
  encoderCount = 0;
  zeroOffset = 0;
  syncEncoderState();
  portEXIT_CRITICAL(&encoderMux);
  moveTargetCount = 0;
  ackBaseDeg = 0.0f;
  Serial.println(F("OK Z"));
}

void printStatus() {
  long pos = readEncoderCount();
  Serial.print(F("POS "));
  Serial.print(pos);
  Serial.print(F(" DEG "));
  Serial.print(countsToDeg(pos), 2);
  Serial.print(F(" CPD "));
  Serial.print(countsPerBaseDeg, 3);
  Serial.print(F(" BUSY "));
  Serial.println(baseBusy ? 1 : 0);
}

void runSweep() {
  const int steps = 28;
  for (int i = 0; i <= steps; i++) {
    float pan = PAN_MIN + (PAN_MAX - PAN_MIN) * ((float)i / (float)steps);
    writeAngles(pan, TILT_CENTER, true);
    delay(80);
  }
  for (int i = 0; i <= steps; i++) {
    float tilt = TILT_MIN + (TILT_MAX - TILT_MIN) * ((float)i / (float)steps);
    writeAngles(PAN_CENTER, tilt, true);
    delay(80);
  }
  writeAngles(PAN_CENTER, TILT_CENTER, true);
}

void handleLine() {
  if (lineLen == 0) return;
  lineBuffer[lineLen] = '\0';

  if (lineLen == 2 && lineBuffer[0] == 'R' && lineBuffer[1] == 'L') {
    panLimitMin = PAN_MIN;
    panLimitMax = PAN_MAX;
    tiltLimitMin = TILT_MIN;
    tiltLimitMax = TILT_MAX;
    Serial.println(F("OK RL"));
    lineLen = 0;
    return;
  }

  if (lineLen == 1) {
    if (lineBuffer[0] == 'H') {
      Serial.println(F("READY"));
      lineLen = 0;
      return;
    }
    if (lineBuffer[0] == '?') {
      printStatus();
      lineLen = 0;
      return;
    }
    if (lineBuffer[0] == 'S') {
      runSweep();
      lineLen = 0;
      return;
    }
    if (lineBuffer[0] == 'Z') {
      zeroBaseReference();
      lineLen = 0;
      return;
    }
    if (lineBuffer[0] == 'X') {
      stopBaseMotion();
      lineLen = 0;
      return;
    }
    if (lineBuffer[0] == 'L') {
      startBaseSpinLeft();
      Serial.println(F("OK L"));
      lineLen = 0;
      return;
    }
    if (lineBuffer[0] == 'R') {
      startBaseSpinRight();
      Serial.println(F("OK R"));
      lineLen = 0;
      return;
    }
    if (lineBuffer[0] == 'U') {
      panLimitMin = 0.0f;
      panLimitMax = 180.0f;
      tiltLimitMin = 0.0f;
      tiltLimitMax = 180.0f;
      Serial.println(F("OK U"));
      lineLen = 0;
      return;
    }
  }

  float pan = panAngle;
  float tilt = tiltAngle;
  float baseDeg = 0.0f;
  float cpdValue = 0.0f;
  bool hasPan = false;
  bool hasTilt = false;
  bool hasBase = false;
  bool baseRelative = false;
  bool hasCpd = false;
  bool hasEncSign = false;
  bool hasJog = false;
  int jogPwm = 0;
  unsigned long jogMs = 250;
  float encSignValue = 1.0f;

  char buf[LINE_BUF_SIZE];
  strncpy(buf, lineBuffer, LINE_BUF_SIZE - 1);
  buf[LINE_BUF_SIZE - 1] = '\0';
  char *token = strtok(buf, " ");
  while (token != NULL) {
    char c = token[0];
    if (c == 'P' || c == 'p') {
      pan = atof(token + 1);
      hasPan = true;
    } else if (c == 'T' || c == 't') {
      tilt = atof(token + 1);
      hasTilt = true;
    } else if (c == 'B' || c == 'b') {
      hasBase = true;
      baseRelative = token[1] == '+' || token[1] == '-';
      baseDeg = atof(token + 1);
    } else if (c == 'C' || c == 'c') {
      hasCpd = true;
      cpdValue = atof(token + 1);
    } else if (c == 'E' || c == 'e') {
      hasEncSign = true;
      encSignValue = atof(token + 1);
    } else if (c == 'J' || c == 'j') {
      hasJog = true;
      jogPwm = atoi(token + 1);
    } else if (c == 'M' || c == 'm') {
      jogMs = (unsigned long)atol(token + 1);
    }
    token = strtok(NULL, " ");
  }

  if (hasCpd) {
    if (setCountsPerBaseDeg(cpdValue)) {
      Serial.print(F("OK C"));
      Serial.println(countsPerBaseDeg, 3);
    } else {
      Serial.println(F("ERR C range"));
    }
  }
  if (hasEncSign) {
    if (setEncoderSign(encSignValue)) {
      Serial.print(F("OK E"));
      Serial.println(encoderSign, 0);
    } else {
      Serial.println(F("ERR E range"));
    }
  }
  if (hasPan || hasTilt) {
    writeAngles(pan, tilt, true);
  }
  if (hasBase) {
    if (baseRelative) {
      startBaseRelativeDeg(baseDeg);
    } else {
      startBaseAbsoluteDeg(baseDeg);
    }
  }
  if (hasJog) {
    startBaseJog(jogPwm, jogMs);
  }
  if (!hasPan && !hasTilt && !hasBase && !hasCpd && !hasEncSign && !hasJog) {
    Serial.println(F("ERR unknown"));
  }
  lineLen = 0;
}

void updateBaseJog() {
  if (!jogActive) return;
  if ((long)(millis() - jogEndMs) >= 0) {
    stopBaseMotion();
  }
}

void updateBaseMotor() {
  if (!moveActive) return;

  unsigned long now = millis();
  if (now - moveStartMs > MOVE_TIMEOUT_MS) {
    stopBaseMotion();
    Serial.println(F("ERR B timeout"));
    return;
  }

  long pos = readEncoderCount();
  long error = moveTargetCount - pos;
  long errAbs = labs(error);
  long traveled = labs(pos - moveStartCount);
  float posDeg = countsToDeg(pos);

  if (fabs(posDeg) > (MAX_ABS_BASE_DEG + ABS_LIMIT_MARGIN_DEG)) {
    stopBaseMotion();
    Serial.println(F("ERR B limit"));
    return;
  }

  long overshootAllowance = max(
    OVERSHOOT_ALLOW_MIN_COUNTS,
    (long)((float)moveMaxTravelCounts * OVERSHOOT_ALLOW_RATIO)
  );
  long plannedDelta = moveTargetCount - moveStartCount;
  bool passedTarget = false;
  if (plannedDelta > 0) {
    passedTarget = pos > (moveTargetCount + ENCODER_TOLERANCE);
  } else if (plannedDelta < 0) {
    passedTarget = pos < (moveTargetCount - ENCODER_TOLERANCE);
  }
  if (traveled > moveMaxTravelCounts + overshootAllowance && passedTarget) {
    overshootCycles++;
  } else {
    overshootCycles = 0;
  }
  if (overshootCycles >= OVERSHOOT_CONFIRM_CYCLES) {
    stopBaseMotion();
    Serial.println(F("ERR B overshoot"));
    return;
  }

  if (errAbs <= ENCODER_TOLERANCE) {
    stopBaseMotion();
    pendingBaseAck = true;
    return;
  }

  // Short breakaway pulse to overcome static friction at move start.
  if (now - moveStartMs < MOVE_KICK_MS) {
    int kick = max(FINE_MIN_PWM, MOVE_KICK_PWM);
    motorDrive(error > 0 ? kick : -kick);
    return;
  }

  if (errAbs < lastErrorAbs - 1 || labs(pos - lastProgressCount) >= STALL_MIN_PROGRESS) {
    lastProgressCount = pos;
    lastProgressMs = now;
    lastErrorAbs = errAbs;
  } else if (now - lastProgressMs > STALL_MS) {
    stopBaseMotion();
    Serial.println(F("ERR B stall"));
    return;
  }

  int pwmCap = (int)constrain((float)errAbs * FINE_PWM_PER_COUNT, (float)FINE_MIN_PWM, (float)COARSE_PWM);

  if (errAbs > COARSE_ERR_COUNTS) {
    motorDrive((error > 0 ? pwmCap : -pwmCap));
    return;
  }

  int out = (int)(FINE_KP * (float)error);
  if (out == 0) {
    out = (error > 0 ? FINE_MIN_PWM : -FINE_MIN_PWM);
  } else if (labs(out) < FINE_MIN_PWM) {
    out = (out > 0 ? FINE_MIN_PWM : -FINE_MIN_PWM);
  }
  if (labs(out) > pwmCap) {
    out = (out > 0 ? pwmCap : -pwmCap);
  }
  motorDrive(out);
}

void setup() {
  pinMode(LED_PIN, OUTPUT);
  digitalWrite(LED_PIN, LOW);

  pinMode(ENC_A_PIN, INPUT);
  pinMode(ENC_B_PIN, INPUT);
  pinMode(MOTOR_AIN1_PIN, OUTPUT);
  pinMode(MOTOR_AIN2_PIN, OUTPUT);
  syncEncoderState();

  ledcSetup(LEDC_PWM_CHANNEL, LEDC_FREQ_HZ, LEDC_RES_BITS);
  ledcAttachPin(MOTOR_PWM_PIN, LEDC_PWM_CHANNEL);
  motorStop();

  Serial.begin(115200);
  Wire.begin(I2C_SDA_PIN, I2C_SCL_PIN);
  Wire.setClock(100000);
  Wire.setTimeOut(50);
  Wire.beginTransmission(0x40);
  if (Wire.endTransmission() == 0) {
    pwm.begin();
    pwm.setOscillatorFrequency(27000000);
    pwm.setPWMFreq(50);
    delay(10);
    pcaReady = true;
  } else {
    Serial.println(F("WARN PCA9685 not found at 0x40"));
  }

  panAngle = PAN_CENTER;
  tiltAngle = TILT_CENTER;
  zeroOffset = 0;
  Serial.println(F("FW head_servo_v5_base"));
  Serial.println(F("READY"));
  Serial.flush();
}

void loop() {
  serviceEncoderLocked();

  while (Serial.available() > 0) {
    char c = Serial.read();
    if (c == '\n' || c == '\r') {
      handleLine();
    } else if (lineLen < LINE_BUF_SIZE - 1) {
      lineBuffer[lineLen++] = c;
    }
  }

  updateBaseMotor();
  updateBaseJog();

  if (spinPwm != 0) {
    motorDrive(spinPwm);
  }

  if (pendingBaseAck) {
    pendingBaseAck = false;
    printBaseAck(ackBaseDeg);
  }

  delay(1);
}

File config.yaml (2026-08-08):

# Voice Agent V5 isolated face tracking head config.

camera:
  face_model_path: face_detection_yunet_2023mar.onnx
  main_res: [1920, 1080]
  detect_res: [1280, 720]
  confidence_threshold: 0.6
  nms_threshold: 0.3
  rotate_180: false
  stream_swap_rb: true
  roi_tracking_enabled: true
  roi_padding_factor: 1.6
  roi_full_scan_interval: 20

hand_fallback:
  enabled: true
  max_hands: 1
  hi_gesture: true
  bye_gesture: true
  wave_threshold: true         # Require waving motion (not just static hand)
  wave_reversals_min: 2        # Minimum swings/reversals to trigger (easier - just 2 swings!)
  wave_amplitude_min: 40.0     # Minimum pixel sweep amplitude
  wave_history_len: 25         # History buffer length for motion detection
  wave_dead_zone_px: 10        # Ignore movements smaller than this

stream:
  enabled: true
  host: "0.0.0.0"
  port: 8081
  fps: 8
  jpeg_quality: 70
  render_fps: 24
  vision_fps: 10
  vision_fps_voice: 0        # fully pause vision during voice (saves ~50ms/frame CPU on Pi)
  vision_pause_on_audio: true # skip camera+YuNet while user/agent audio is active
  res: [320, 180]

debug_viz:
  enabled: true
  auto_start: true
  host: "0.0.0.0"
  port: 8082
  manual_control_enabled: false  # true = browser WASD/Z/R work alongside face tracking
  head_step_deg: 5.0
  map_poll_ms: 30
  base_yaw_sign: 1.0          # flip 3D base rotation in world frame
  pan_yaw_sign: -1.0          # 3D neck pan; flip if viz pan left/right is mirrored
  tilt_sign: 1.0              # flip head tilt (W/S); flip to -1.0 if viz tilts opposite
  imu_pitch_sign: -1.0        # flip IMU pitch chip on head mesh

person_memory:
  enabled: true
  timeout_sec: 20.0
  merge_angle_deg: 12.0
  camera_hfov_deg: 62.0
  camera_vfov_deg: 37.0
  max_items: 6
  track_gain: 0.75
  max_pan_step_deg: 10.0
  reacquire_angle_deg: 28.0
  reacquire_after_sec: 5.0   # keep normal tracking/search first; then go to memory instead of wander
  face_confidence: 1.0
  base_enabled: true
  base_min_yaw_error_deg: 10.0
  base_min_step_deg: 1.5
  base_max_step_deg: 2.5
  base_yaw_to_step_gain: 0.08
  base_cooldown_sec: 3.0
  base_compensation_gain: 0.55

last_seen_search:
  enabled: true
  edge_norm: 0.40              # face/body near frame edge → remember exit direction
  timeout_sec: 5.0             # search last-seen bearing until this (then memory/wander)
  track_gain: 0.65
  max_pan_step_deg: 8.0
  base_enabled: true
  base_min_yaw_error_deg: 8.0
  base_min_step_deg: 1.5
  base_max_step_deg: 2.5
  base_yaw_to_step_gain: 0.08
  base_cooldown_sec: 2.5
  base_compensation_gain: 0.50
  edge_track_base: true        # only when pan is stuck at limit

imu:
  enabled: true
  auto_level_on_start: true   # zero pitch/roll at startup upright pose
  auto_level_sec: 2.0         # still-sample window after servos settle
  auto_level_settle_sec: 0.8  # wait after T112 upright before IMU samples
  auto_level_warmup_sec: 0.3   # filter settle after IMU thread starts
  auto_level_gyro_max_dps: 8.0  # only average low-motion samples
  auto_level_min_samples: 40
  i2c_bus: 1
  address: 0x69
  sample_hz: 100
  roll_pitch_alpha: 0.02
  # PCB on head: +X up, +Y left, +Z back → forward=-Z, left=+Y, yaw-about-up=+X
  # Values are 1-based sensor axes (1=X, 2=Y, 3=Z); negative flips sign.
  axis_remap: [-3, 2, -1]
  # Used only when auto_level_on_start is false (manual test_imu.py calibration)
  roll_offset_deg: -7.34
  pitch_offset_deg: 12.84
  horizon_tilt_gain: 0.85
  horizon_tilt_sign: -1.0   # keep camera horizontal; flip if tilt runs wrong way
  horizon_pitch_bias_deg: 0.0
  horizon_pitch_smooth_hz: 3.5
  horizon_max_bias_deg: 6.0
  horizon_max_pitch_deg: 18.0
  horizon_gyro_max_dps: 45.0       # ignore horizon when spinning/moving
  horizon_max_up_from_center_deg: 2.0
  horizon_max_down_from_center_deg: 4.0
  horizon_relevel_after_sec: 0.0   # unused — IMU horizon applies continuously when idle
  yaw_sign: -1.0             # flip if IMU yaw integral opposes encoder/base
  drift_correction_enabled: true
  drift_stationary_hold_sec: 0.35
  drift_enc_stable_deg: 0.2
  drift_pan_stable_deg: 0.2
  drift_gyro_max_dps: 6.0
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

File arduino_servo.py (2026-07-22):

"""Minimal ESP32 serial transport for Voice Agent V5 head pan/tilt servos."""

from __future__ import annotations

from dataclasses import dataclass
import os
import re
import time
from typing import Optional, Tuple

try:
    import serial
except ImportError:  # pragma: no cover - runtime dependency on the Pi
    serial = None  # type: ignore

DEFAULT_PORTS = ("/dev/ttyUSB0", "/dev/ttyUSB1", "/dev/ttyACM0")
BOOT_CPD = 1.0
READY_TIMEOUT_SEC = 5.0
ACK_TIMEOUT_SEC = 1.0
BASE_MOVE_TIMEOUT_SEC = 15.0
MIN_SEND_INTERVAL_SEC = 0.02
SERVO_SEND_MIN_DEG = 0.06
SERVO_SEND_HZ = 25.0
SERVO_ANGLE_QUANTUM_DEG = 0.2
_SERVO_ACK_RE = re.compile(r"^OK\s+P(-?\d+)\s+T(-?\d+)\s*$")
_ARM_HOME_RE = re.compile(r"^HOME\s+A0=")
_BASE_ACK_RE = re.compile(r"^OK\s+B(-?\d+(?:\.\d+)?)\s*$")
_OK_C_RE = re.compile(r"^OK\s+C(-?\d+(?:\.\d+)?)\s*$")
_OK_E_RE = re.compile(r"^OK\s+E(-?\d+)\s*$")
_BASE_STATUS_RE = re.compile(
    r"^POS\s+(-?\d+)\s+DEG\s+(-?\d+(?:\.\d+)?)\s+CPD\s+(-?\d+(?:\.\d+)?)\s+BUSY\s+([01])\s*$"
)
_PROX_EVENT_RE = re.compile(
    r"^PROX\s+A=([LCR])\s+V=(-?\d+)\s+D=(\d+)\s+C=(\d+)\s*$"
)
_PROX_DEPART_RE = re.compile(
    r"^PROX\s+D=([LCR])\s+V=(-?\d+)\s+D=(\d+)\s+C=(\d+)\s*$"
)
_PROX_CLEAR_RE = re.compile(r"^PROX\s+CLEAR\s*$")
_ZONE_RE = re.compile(r"^ZONE\s+L=([01])\s+C=([01])\s+R=([01])\s*$")


@dataclass(frozen=True)
class BaseStatus:
    encoder_count: int
    degrees: float
    counts_per_degree: float
    busy: bool


def _quantize_servo_angle(deg: float, quantum: float = SERVO_ANGLE_QUANTUM_DEG) -> float:
    q = quantum
    return round(deg / q) * q


def resolve_port(port: str) -> list[str]:
    if port:
        if os.path.exists(port):
            return [port]
        fallbacks = [p for p in DEFAULT_PORTS if os.path.exists(p)]
        if fallbacks:
            print(f"Configured serial port {port} not found; using {fallbacks[0]} instead")
            return [fallbacks[0]]
        return [port]
    return [p for p in DEFAULT_PORTS if os.path.exists(p)]


class ArduinoServoLink:
    """USB serial link to v5 ESP32 PCA9685 head-servo firmware."""

    def __init__(self, port: str = "", baud: int = 115200):
        self._port_name = port
        self._baud = baud
        self._ser: Optional[serial.Serial] = None
        self._connected = False
        self._last_pan: Optional[float] = None
        self._last_tilt: Optional[float] = None
        self._last_a0: Optional[float] = None
        self._last_a1: Optional[float] = None
        self._last_a2: Optional[float] = None
        self._last_a3: Optional[float] = None
        self._last_base_ack: Optional[float] = None
        self._last_send_ts = 0.0
        self.servo_send_min_deg = SERVO_SEND_MIN_DEG
        self.servo_send_hz = SERVO_SEND_HZ
        self.servo_angle_quantum_deg = SERVO_ANGLE_QUANTUM_DEG
        self.home_smooth_sec = 0.9
        self.home_smooth_hz = 30.0
        self.base_command_scale = 1.0
        self.encoder_sign = -1.0
        self.base_move_timeout_sec = BASE_MOVE_TIMEOUT_SEC
        self.last_base_error: Optional[str] = None
        self._error_logged = False
        self._boot_banner = ""
        self._prox_callback = None  # callable(line: str) for PROX/ZONE events

    def firmware_banner(self) -> str:
        return self._boot_banner

    def arm_firmware_hint(self) -> str:
        banner = self._boot_banner
        if "head_servo_hands" in banner:
            return ""
        if "head_servo_v5_base" in banner:
            return (
                "Detected head-only firmware (FW head_servo_v5_base). "
                "Flash firmware/head_servo_hands/ for arm servos."
            )
        return (
            "ESP32 did not answer V with HOME A0=... "
            "(wrong sketch, serial noise, or retry after reboot)."
        )

    @property
    def connected(self) -> bool:
        return self._connected and self._ser is not None

    def _drain_rx(self) -> None:
        if self._ser is None:
            return
        try:
            while self._ser.in_waiting:
                line = self._ser.readline().decode("utf-8", errors="ignore").strip()
                if not line:
                    break
                # Route PROX / ZONE events to registered callback
                if (line.startswith("PROX") or line.startswith("ZONE")) and self._prox_callback:
                    try:
                        self._prox_callback(line)
                    except Exception:
                        pass
        except Exception:
            pass

    def _wait_for_ready(self, timeout_sec: float) -> bool:
        if self._ser is None:
            return False
        old_timeout = self._ser.timeout
        # Poll in non-blocking mode; some ESP32 boots stream binary noise and
        # never emit a clean newline, which can stall readline()-based handshakes.
        self._ser.timeout = 0
        deadline = time.time() + timeout_sec
        buf = ""
        try:
            while time.time() < deadline:
                waiting = self._ser.in_waiting
                chunk = self._ser.read(waiting if waiting > 0 else 64)
                if chunk:
                    buf += chunk.decode("utf-8", errors="ignore")
                    if len(buf) > 2048:
                        buf = buf[-1024:]
                    self._boot_banner = buf
                    if "READY" in buf or "FW head_servo" in buf:
                        return True
                time.sleep(0.02)
            return False
        finally:
            self._ser.timeout = old_timeout

    def _handshake(self) -> bool:
        if self._ser is None:
            return False
        if self._wait_for_ready(1.2):
            return True
        self._ser.write(b"H\n")
        self._ser.flush()
        return self._wait_for_ready(READY_TIMEOUT_SEC)

    def connect(self) -> bool:
        if serial is None:
            print("pyserial not installed; install with: python -m pip install pyserial")
            return False

        ports = resolve_port(self._port_name)
        if not ports:
            print(f"No ESP32 serial ports found ({', '.join(DEFAULT_PORTS)}).")
            return False

        for port in ports:
            try:
                self._ser = serial.Serial(port, self._baud, timeout=0.12, write_timeout=1.0)
                time.sleep(0.4)
                if self._handshake():
                    self._connected = True
                    self._error_logged = False
                    self._drain_rx()
                    print(f"ESP32 head servo ready on {port}")
                    return True
                print(f"No READY from ESP32 on {port}")
                self.close(skip_home=True)
            except Exception as e:
                if not self._error_logged:
                    print(f"ESP32 serial connect failed ({port}): {e}")
                    self._error_logged = True
                self.close(skip_home=True)
        return False
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

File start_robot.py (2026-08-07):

"""Main entry point for the modular Voice Agent V5."""

from __future__ import annotations

import os
import signal
import sys

import typing
if not hasattr(typing, 'TypeAlias'):
    try:
        from typing_extensions import TypeAlias
        typing.TypeAlias = TypeAlias
    except ImportError:
        typing.TypeAlias = typing.Any

import threading
import time
from pathlib import Path

from base_safety import BaseMotionGate
from core.blackboard import Blackboard
from core.face_tracking import FaceTracker
from core.imu_service import ImuService
from core.servo_loop import ServoLoop
from core.base_controller import BaseController
from core.servo_mixer import ServoMixer
from core.arm_controller import ArmController
from core.emotion_engine import EmotionEngine
from core.eye_renderer import EyeRenderer
from core.debug_dashboard import DebugDashboard
from core.animation_engine import AnimationEngine  # optimize/cpu2
from core.tof_state import STATE as TOF_STATE
from core.tof_stream import TofStreamHandler
from core.yaw_pose import (
    lock_head_home,
    lock_home_tracker,
    publish_tof_viz_pose,
    publish_tracker_pose,
    query_enc,
    resnap_tracker_after_spin,
    update_tracker,
)
from lib.yaw_home_tracker import YawHomeTracker
from lib.base_home_drive import drive_base_to_imu_zero
from lib.head_mech import signed_pan_mech_deg
from lib.live_tune import load_tune_defaults_from_config, sanitize_config
from hardware.arduino_servo import ArduinoServoLink
from base_motor_utils import apply_base_calibration_to_nano

APP_DIR = Path(__file__).resolve().parent
DEFAULT_CONFIG_PATH = APP_DIR / "config.yaml"

try:
    import yaml
except ImportError:
    yaml = None


def _load_yaml(path: Path) -> dict:
    if yaml is None or not path.exists():
        return {}
    with open(path, encoding="utf-8") as f:
        return sanitize_config(yaml.safe_load(f) or {})


def _wait_imu_ready(bb: Blackboard, timeout_sec: float = 12.0) -> None:
    deadline = time.time() + timeout_sec
    while time.time() < deadline:
        state = bb.read("imu_calibrated")
        if state["imu_calibrated"]:
            return
        time.sleep(0.05)
    print("[Bootstrap] WARNING: IMU calibration wait timed out.")


def _print_yaw_decomposition(bb: Blackboard) -> None:
    """Log YawHomeTracker pose locked at startup."""
    state = bb.read(
        "base_encoder_deg",
        "body_yaw_deg",
        "head_yaw_on_body_deg",
        "from_home_enc_deg",
        "from_home_imu_deg",
        "disagreement_deg",
        "base_world_yaw_deg",
        "imu_available",
    )
    print("[Bootstrap] Yaw model (HOME = 0° at startup forward):")
    print(f"  encoder raw       {state['base_encoder_deg']:+.1f}°")
    if state["imu_available"]:
        print(
            f"  FROM HOME enc     {state['from_home_enc_deg']:+.1f}°"
            f"  |  imu {state['from_home_imu_deg']:+.1f}°"
            f"  Δ {state['disagreement_deg']:+.1f}°"
        )
        print(
            f"  body (imu)        {state['body_yaw_deg']:+.1f}°"
            f"  |  pan-on-body {state['head_yaw_on_body_deg']:+.1f}°"
        )
        print(f"  world aim         {state['base_world_yaw_deg']:+.1f}°")
    else:
        print("  IMU off — world yaw = encoder + servo pan")
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

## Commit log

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2026-06-17 Strip IMU from main; keep face tracking stable.
    Remove BMI160 integration from the default entrypoint, fix elastic base motion, and point IMU work to feature/imu.
    [base_safety.py, config.yaml, face_tracking_head.py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]
2026-06-18 Fix base calibration and smooth head servo motion.
    Add encoder sign and plate command_scale so B moves match real degrees, centralize calibration in base_motor_utils, and simplify face-tracking base to one-shot plate-degree commands. Tune elastic servo glide and steady serial streaming to remove stop-go jitter.
    [arduino_servo.py, base_motor_utils.py, config.yaml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]
2026-06-18 Tune base plate-degree scaling and larger auto nudges.
    Set command_scale to 0.6 from measured 20°→5° plate mapping, increase 5–12° tracking steps, fix correct-move scaling, and add firmware minimum move counts with improved busy handling.
    [arduino_servo.py, base_motor_utils.py, config.yaml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]
2026-06-18 Add head-lead rule so base follows neck direction.
    Require the head to turn toward interest before base nudges, match base rotation to pan offset, and flip base sign for correct plate direction.
    [config.yaml, face_tracking_head.py]
2026-06-18 Replace elastic head motion with exponential smoothing.
    Drop velocity spring glide and goal deadband so pan/tilt follow targets smoothly without resistance or shiver.
    [config.yaml, elastic_head_motion.py, face_tracking_head.py]
2026-06-18 Tune wander search for small steps and shorter pauses.
    Use incremental pan/tilt glances without teleport jumps, moderate step size and follow speed, and shorter hold times between looks.
    [config.yaml, elastic_head_motion.py, face_tracking_head.py]
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2026-06-19 Add last-seen corner search, person memory, and IMU yaw viz fix.
    Track exit bearings with base-assisted search after edge loss, decompose IMU yaw into base vs pan for debug viz, and fix 3D rotation using encoder base only.
    [base_safety.py, base_yaw_controller.py, config.yaml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]
2026-06-19 Reduce base rotation overshoot during face tracking.
    Use mechanical pan compensation, cap steps by aim error, and tune smaller base moves with higher neck counter-rotation.
    [config.yaml, face_tracking_head.py]
2026-06-20 Fix ESP32 serial connect in modular entry point.
    Use the correct baud kwarg, call connect(), and honor empty port as auto-detect so head servos no longer run in dry-run mode.
    [start_robot.py]
2026-06-20 Fix base motor direction and recalibrate plate command scale.
    Swap TB6612 direction pins so both rotation directions drive reliably, restore encoder_sign -1 and zero_on_start false from main, and tune command_scale to 0.1714 after measuring 10° cmd vs 35° actual.
    [config.yaml, head_servo.ino, start_robot.py]
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2026-06-20 Fix base runaway, re-enable IMU horizon leveling, and smooth tilt motion.
    Cap base steps and chunk random turns, sync encoder on startup, improve watchdog slip detection, wire HorizonTiltBias into ImuService, and soften wander/tilt servo output.
    [base_controller.py, base_safety.py, blackboard.py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]
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2026-06-20 Switch base motor control to L/R spin like robottest.
    Replace unreliable closed-loop B moves with encoder-stopped spin in ServoMixer and tests, add firmware L/R/RL commands, robottest keyboard script, and fix recenter direction.
    [arduino_servo.py, base_controller.py, base_spin_motion.py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]
2026-06-20 Send base calibration to ESP32 on startup to fix ERR B limit lockout
    [start_robot.py]
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2026-06-21 Add head-lead base control, safer spin stops, and snappier head motion.
    Lock yaw reference at startup, enforce base-follows-head direction, resync IMU fusion after spins, and stop L/R spins on encoder stall so wander moves stay near 10° instead of running away.
    [arduino_servo.py, base_controller.py, base_spin_motion.py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]
2026-06-21 Fix 3D debug viz to show base and head separately.
    Wire config-driven mech angles and IMU fields into the dashboard API, add base arrow/world-aim visuals, and serve on debug_viz port from config.
    [debug_dashboard.py, head_debug_viz.py, start_robot.py]
2026-06-21 Integrate IMU fusion, signed pan/tilt, and self-hosted 3D debug viz into start_robot.
    Port test harness learnings to production: encoder–IMU drift correction, pan_sign-aware base control, optional browser debug commands, and local Three.js serving so the dashboard works offline.
    [base_controller.py, base_yaw_controller.py, blackboard.py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]
2026-06-21 Add three-layer yaw decomposition for debug viz and start_robot.
    Split yaw into fixed true north, encoder body, and IMU head-on-body so the 3D
    HUD matches physical motion. Wire decomposition through ImuService, blackboard,
    and bootstrap fusion lock; keep ServoMixer from overwriting decomposed world yaw.
    [base_controller.py, base_yaw_controller.py, blackboard.py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]
2026-06-21 Fix spurious track pan and increase base follow step size.
    Use filtered bearing for pan hold band, ramp base neck comp during track,
    apply pan_track_sign correctly, and bump base nudge steps by ~5°.
    [config.yaml, servo_loop.py]
2026-06-21 Port v4 surroundings emotion system and keep TFT eyes fixed at center.
    Bring over full emotion presets, intensity mapping, and distance/directional
    selection while head servos handle gaze — no face-driven eye position or rotation
    on the displays.
    [config.yaml, emotion_engine.py, emotion_presets.py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]
2026-06-21 Fix white glow under eyebrows by porting v4 eyelid overdraw.
    Use wider opaque lid masks with solid rotation so semi-transparent
    bicubic fringe no longer reveals white eye pixels beneath the brow.
    [eye_renderer.py]
2026-06-21 Improve wander handoff, tilt glances, and no-face emotion timing.
    Seed wander from the last track pose instead of pan center, add visible
    tilt steps with light IMU blend, cap fast-track pan overshoot, and delay
    sad until ~2.5 minutes without a face.
    [config.yaml, emotion_engine.py, servo_loop.py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]
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2026-06-22 Detach arm servo PWM when idle to stop SG90 buzz and heat.
    Arms energize only on A0-A3 commands and auto-off after 1.5s; AO/detach_arms
    for immediate release. Head pan/tilt behavior is unchanged.
    [arduino_servo.py, head_servo_hands.ino]
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2026-06-23 Fix vertical face tracking when the face sits below frame center.
    Expand downward tilt travel (tilt_min 75) and improve track-mode tilt control with a dedicated bearing filter, asymmetric range caps, and per-tick step limits matching pan tracking.
    [config.yaml, head_servo.ino, servo_loop.py]
2026-06-23 Fix false wrong_dir base spin faults when encoder_sign is -1.
    Validate closed-loop spin progress against plate_deg × encoder_sign so correct physical moves are not rejected when encoder DEG opposes the command sign.
    [base_spin_motion.py, servo_mixer.py]
2026-06-23 Fix IMU horizon behavior in wander mode after face tracking.
    Sync tilt smooth to the IMU target when leaving track, use the wander IMU blend during forward return, and gently relevel between glances to avoid a long slow tilt-up recovery.
    [config.yaml, servo_loop.py]
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2026-06-23 Fix arm homing on safe jogger exit.
    Smooth-blend arms to home on Q/Ctrl+C and wait 1.5s before PWM detach
    so servos finish moving before the link closes.
    [arduino_servo.py]
2026-06-23 Add production arm lean on base turns and fix left-arm calibration.
    Wire ArmController through ServoMixer with keepalive, correct left raise/sweep keys and A1 home at 65°, and update head_servo_hands firmware v14.
    [arduino_servo.py, arm_controller.py, arm_safety_envelope.py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]
2026-06-23 Fix smooth arm homing on start_robot shutdown.
    Wait for worker threads before serial close, blend head and arms to home together, and surface homing errors instead of swallowing them.
    [arduino_servo.py, start_robot.py]
2026-06-23 Match shutdown homing to safe jogger and fix Ctrl+C regression.
    Use shared smooth arm blend in start_robot, restore inline homing in test_servo_arms_safe, and skip duplicate close() homing after exit.
    [arduino_servo.py, start_robot.py]
2026-06-23 Fix LiveKit voice integration for threaded start_robot shutdown.
    Run AgentServer in-process with THREAD executor so Blackboard writes work without the CLI signal-handler crash, drain sessions cleanly on Ctrl+C, and enable voice in config with dev/start mode selection.
    [config.yaml, start_robot.py]
2026-06-24 Fix laggy eyes and buggy blinks during LiveKit voice sessions.
    Use transient amplitude scale punch instead of mutating lid targets, stabilize conv emotion changes, and reduce idle Blackboard writes from the TTS pacer.
    [emotion_engine.py, eye_renderer.py]
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2026-06-24 fix: VL53L0X driver, hot-plug recovery, and ToF test tooling
    Switch firmware from VL53L1X to Adafruit VL53L0X for GY-VL53L0XV2 hardware, add periodic mux reprobe and I2C bus recovery so sensors work after replug without resetting the ESP, and add a live web viz plus serial port auto-detect.
    [head_servo_hands.ino]
2026-06-24 fix: smooth ToF at max range and suppress false approach jitter
    Add averaged trusted-range filtering (80–1800 mm) in the viz, test firmware, and production approach logic so max-range flicker no longer reads as rapid approach.
    [head_servo_hands.ino]
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2026-06-24 feat: integrate ToF proximity with search and glance behaviors
    - Add TM/TU serial mute commands to firmware to prevent false ToF triggers during rotation
    - Implement post-motion blanking window in base controller
    - Add prox_search_active behavior to Wander mode (head sweeps to center)
    - Add prox_glance_active overlay to Track mode (briefly glances during conversation)
    - Add proximity metrics and state to the 3D debug dashboard
    [arduino_servo.py, base_controller.py, blackboard.py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]
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2026-06-24 fix: add ToF mute and PROX parsing to hardware/arduino_servo
    start_robot imports hardware.arduino_servo, which lacked mute_tof/unmute_tof
    and PROX/ZONE serial handling used by ServoMixer during base motion.
    [arduino_servo.py, servo_mixer.py]
2026-06-24 fix: resolve import error in servo_mixer for PROX lines and reduce confidence threshold
    [config.yaml, servo_mixer.py]
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2026-06-24 fix: restore fast serial drain so PROX flood does not block servos
    Line-by-line _drain_rx stalled head and base commands under continuous
    ToF output; flush the buffer before sends and poll PROX in ServoMixer.
    [arduino_servo.py, servo_mixer.py]
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2026-06-24 feat: mirror ToF L/R zones and add 3D proximity debug viz
    Swap prox zone labels when side sensors are mounted opposite mux channels,
    and show ToF presence/approach beams plus an overlay HUD on the 3D model.
    [config.yaml, head_debug_viz.py, servo_mixer.py]
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2026-06-29 feat: add yaw HOME viz harness, ToF approach streaming, and L/R base homing
    Add yaw_robot_viz with encoder/IMU debug dashboard and robottest-style controls;
    stream ToF at 5Hz for live viz; approach harness with fused bearing turns; fix
    post-spin IMU resync without re-locking startup forward; homing via L/R spins.
    [arduino_servo.py, config.yaml, head_servo_hands.ino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]
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2026-06-29 fix: reduce IMU HOME overshoot with shorter bursts and early braking
    Stop L/R homing bursts when most of the yaw error is closed, brake on
    low gyro near target, and scale down after crossing zero to prevent
    ±40° oscillation seen in HOME return logs.
    [config.yaml]
2026-06-29 fix: stop viz pose thread from starving serial during base spins
    Serialize ESP32 serial IO with a lock, publish viz pose from IMU + cached
    encoder only, and reserve query_status for the control loop so spins
    no longer fail with no_start / bad file descriptor errors.
    [arduino_servo.py]
2026-06-29 fix: improve approach ToF aim accuracy and still-person tracking
    Correct spin sign via base.sign, reject post-motion ghost bearings, and use distance-scaled undershoot so close targets aim spot-on while far targets stay conservative.
    [config.yaml]
2026-06-29 feat: integrate YawHomeTracker and ToF 3D map into start_robot dashboard.
    Replace head-debug viz with ESP32 ToF stream + IMU-primary pose on port 8082, and fix static serving for cache-busted .mjs URLs.
    [blackboard.py, config.yaml, debug_dashboard.py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]
2026-06-29 fix: compact debug dashboard and encoder-primary map yaw
    Redesign the debug UI as a single non-scrolling viewport with a smaller
    camera sidebar, mode badge, and compact ToF readouts. Use encoder yaw for
    map localization so HOME tracks the base correctly when IMU drifts, re-anchor
    the tracker on IMU integral reset, and return base to forward on shutdown.
    ToF readings continue to be ignored while the base is moving or settling.
    [debug_dashboard.py, servo_mixer.py, start_robot.py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]
2026-06-30 fix: stabilize eye display and raise refresh to 40 fps
    Clamp blink paste coords to prevent PIL overflow glitches, add dedicated
    eyes.render_fps with frame pacing, and show CPU load on the debug dashboard.
    [config.yaml, debug_dashboard.py, eye_renderer.py]
2026-06-30 fix: faster approach confirm and clean Ctrl+C shutdown
    Lower ESP32 APPROACH_CONFIRM_FRAMES to 2 for quicker PROX events, and
    replace sys.exit in the signal handler with a one-shot shutdown event.
    [head_servo_hands.ino, start_robot.py]
2026-06-30 Fix customize button eye color via HTTP blackboard API.
    Add POST /api/eye-color on the media server and start it with the shared blackboard so the kiosk palette button updates TFT eyes without a LiveKit session.
    [start_robot.py]
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2026-07-01 fix: yaw viz head/base model and stop base drift on head pan.
    Add pink head disc with mech pan from HOME, lock base yaw to encoder during head-only motion, and gate IMU snap until pan is stable.
    [start_robot.py, yaw_pose.py]
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2026-07-02 Improve yaw robot 3D viz with belly torso and visible eyes.
    Replace heading arrows with front-facing eyes placed outside the head mesh bevel, and tune arm blend rate for smoother motion.
    [config.yaml]
2026-07-02 Add dual-speed arm movements for talk gestures
    - a0, a1 (vertical/up-down) use vertical_speed (default 0.8x - slower)
    - a2, a3 (horizontal/swap) use horizontal_speed (default 1.5x - faster)
    - Smooth interpolation between poses with different speeds per motor group
    - Configurable in config.yaml under talk_gesture section
    - Creates more natural hand gestures while talking
    [config.yaml, start_robot.py, talk_gesture_service.py]
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2026-07-02 Complete dual-speed arm movements for bye wave animations
    - Read vertical_speed and horizontal_speed from talk_gesture config
    - Pass speed parameters to _ByeSequenceRunner constructor
    - Bye wave animations now use same dual-speed interpolation as talk gestures
    - a0/a1 (vertical up/down) move at 0.8x speed (slower, more deliberate)
    - a2/a3 (horizontal swap) move at 1.5x speed (faster, more expressive)
    [bye_wave_service.py]
2026-07-02 fix: approach ToF viz, HOME delay, and spin direction.
    Port yaw HOME pose fields to the approach dashboard, show clear-wait and homing states, keep ToF targets in world frame while the robot model rotates, and stop inverting ToF bearing with base.sign so physical turns match the viz.
    [config.yaml, tof_state.py, yaw_pose.py]
2026-07-02 fix: align approach map heading with encoder-based true front.
    Approach bearing spins are encoder-closed-loop; use viz_base_yaw_deg for ToF map rotation so the robot front marker matches physical heading while yaw test viz keeps IMU.
    [tof_state.py, yaw_pose.py]
2026-07-02 Reduce horizontal speed from 1.5 to 1.0 to fix bye wave frame skipping
    - horizontal_speed reduced from 1.5x to 1.0x (normal speed)
    - Prevents a2/a3 (wrist/hand swap) from moving too fast
    - Fixes frame skipping during bye wave animations (53->48->53 waves)
    - vertical_speed remains at 0.8x (slower, deliberate up/down movements)
    - Dual-speed still active: vertical moves slower, horizontal at normal pace
    [config.yaml]
2026-07-02 fix: base follow when head pan hits servo limit during face track.
    Detect hardware pan stops and use aim-driven limit steps with shorter cooldown so the base keeps turning toward off-center targets after the neck is exhausted.
    [base_controller.py, config.yaml]
2026-07-02 fix: apply IMU horizon tilt leveling during face track.
    Use effective_tilt_center for track tilt targets, follow horizon at full rate while tracking, and widen horizon bias limits so pitch correction is visible.
    [config.yaml, servo_loop.py]
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2026-07-02 fix: IMU horizon leveling in wander, mechanical tilt during face track.
    Use full IMU effective tilt center in wander idle relevel and glance reference; freeze pitch at mechanical center while tracking so face tilt PID is not pulled by horizon correction.
    [config.yaml, servo_loop.py]
2026-07-02 Fix AttributeError by initializing animation state variables on Blackboard
    - Initialize bye_animation_playing, bye_animation_name, bye_animation_current_frame, bye_animation_total_frames
    - Prevents AttributeError when reading animation state before first animation plays
    - Variables initialized to safe defaults (False, empty string, 0, 0)
    [bye_wave_service.py]
2026-07-02 Add animation state fields to Blackboard class definition
    - Added bye_animation_playing (bool) - tracks if animation is executing
    - Added bye_animation_name (str) - current animation name (bye1/bye2/bye3)
    - Added bye_animation_current_frame (int) - current frame index
    - Added bye_animation_total_frames (int) - total frame count
    - Fields must be defined at class level for Blackboard.write() to work
    - Fixes AttributeError when trying to write animation state
    [blackboard.py]
2026-07-02 fix: flip viz base_yaw_sign so map spin matches physical robot.
    Set debug_viz.base_yaw_sign to +1 so robot.rotation.y follows encoder heading in the same direction as the real base.
    [config.yaml]
2026-07-02 fix: only queue face greetings when LiveKit session is active.
    Skip stale greeting seq on voice connect and guard session.say until AgentSession is running to avoid "AgentSession isn't running" errors before a client connects.
    [face_greeting.py]
2026-07-02 Add interactive debug interface with adjustable arm speeds
    Features:
    - Real-time speed adjustment sliders in web interface
    - Vertical speed slider (0.3x - 1.5x) for a0/a1 movements
    - Horizontal speed slider (0.3x - 2.0x) for a2/a3 movements
    - Live preview of arm positions and animation state
    - Reset to defaults button
    - Save to config.yaml button (persists across restarts)
    - API endpoints:
    * GET /api/get_speeds - retrieve current speeds
    * POST /api/set_speeds - update speeds in real-time
    * POST /api/save_to_config - write speeds to config.yaml
    - Beautiful dark UI matching robot theme
    - All changes apply immediately to running animations
    Access at http://raspberrypi.local:8000
    [bye_wave_service.py]
2026-07-02 Fix speed control logic to work intuitively (lower = slower)
    BREAKING CHANGE: Speed values now work intuitively
    - Lower values (0.3x) = SLOWER movements (longer duration)
    - Higher values (2.0x) = FASTER movements (shorter duration)
    - 1.0x = normal speed
    Technical changes:
    - Use inverse relationship: duration = base_duration / speed
    - Vertical and horizontal motors can have different durations
    - Frame duration is the max of both to ensure smooth completion
    - Added safety minimum of 0.1x to prevent division errors
    - Updated UI help text to clarify: 'Lower = SLOWER'
    Now 0.3x will make movements much slower (3.3x longer duration)
    Users can adjust down to 0.3x for very slow, deliberate animatio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
    [bye_wave_service.py]
2026-07-02 Fix config save to preserve all sections and formatting
    Problem: yaml.safe_dump() was rewriting entire config and losing sections
    Solution: Use regex to update only the specific values in talk_gesture section
    - Preserves all comments, formatting, and other config sections
    - Only updates vertical_speed and horizontal_speed values
    - Prevents corruption of surroundings_emotion and other sections
    - Fixes TypeError: float() argument must be a string or a real number
    Users who clicked 'Save to Config' before this fix will need to
    restore their config.yaml from git or backup
    [bye_wave_service.py]
2026-07-02 Add continuous smooth motion for a2/a3 motors (wrist/hand)
    Improvements for fluid, continuous arm movements:
    1. Increased update rate: 50Hz → 100Hz (poll_interval: 0.02s → 0.01s)
    - 2x more position updates per second
    - Eliminates steppy/jerky motion
    - Creates continuous smooth movement
    2. Added cubic ease-in-out easing function
    - Smooth acceleration at start
    - Smooth deceleration at end
    - Prevents abrupt starts and stops
    - Formula: cubic for first half, inverse cubic for second half
    3. Applied to both services:
    - bye_wave_service.py (bye animations)
    - talk_gesture_service.py (talking gestures)
    4. Consistent with dual-speed system:
    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
    [bye_wave_service.py, talk_gesture_service.py]
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2026-07-02 Pause head movement (servo_pan/servo_tilt) during bye wave animations
    - Added bye_wave_active check in servo_loop main loop
    - Head (pan/tilt) now holds position while bye animation plays
    - Prevents head from tracking/wandering during hand wave
    - Matches existing arm_controller behavior (already paused during bye)
    - Creates focused, stable bye wave gesture
    When user waves hand near face:
    - Bye animation triggers
    - bye_wave_active = True on Blackboard
    - Servo loop pauses (head holds position)
    - Arm animation plays smoothly
    - bye_wave_active = False when done
    - Head resumes normal tracking/wandering
    Head will stay still and focused during the entire bye wave! 👋
    [servo_loop.py]
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2026-07-02 Add debug logging to face greeting arm service
    - Added detailed DEBUG logs to trace face detection flow
    - Fixed face ROI extraction (pixel coordinates from FaceTracker)
    - Added traceback on errors
    - Will help diagnose why greetings aren't triggering
    [face_greeting_arm.py]
2026-07-02 Fix face ROI extraction - use normalized coordinates
    PROBLEM: Face bbox coordinates were in detection resolution (1280x720)
    but stream_frame is in stream resolution (320x180). Coordinates like
    x=783 exceed frame width of 320, causing 'Invalid ROI bounds'.
    SOLUTION: Use normalized coordinates (norm_x, norm_y, area_ratio) which
    work across any resolution. Calculate pixel coordinates from normalized
    center position and estimated face size from area_ratio.
    This fixes greeting detection - face ROI will now extract correctly!
    [face_greeting_arm.py]
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2026-07-02 feat: Improve face recognition with landmarks + LBP + ServoMixer integration
    Major improvements to face greeting system:
    1. FACE RECOGNITION UPGRADE:
    - Use YuNet facial landmarks (5 points: eyes, nose, mouth) for geometric features
    - Add Local Binary Patterns (LBP) for texture-based recognition
    - Combine landmarks + LBP + color histograms for multi-feature embedding
    - Improves accuracy from ~70% to ~90%+ (estimated)
    - More robust to lighting changes (LBP is illumination-invariant)
    - More robust to pose/expression changes (landmarks capture facial structure)
    2. MOTOR CONTROL FIX:
    - Fixed test_face_greeting_arm.py to properly integrate ServoMixer
    - Start ServoMixer in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
    [config.yaml, face_greeting_arm.py, face_tracking.py]
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
